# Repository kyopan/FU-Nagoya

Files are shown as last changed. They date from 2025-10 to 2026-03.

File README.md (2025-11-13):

**プロジェクトID**: FU

# Fragmentations of Unity (FU)

> 名古屋市芸術創造センター 群ロボットインスタレーション

---
project-type: customer
status: 🟢 稼働中
phase: Development
priority: Medium
start-date: 2025-10-13
updated: 2025-10-28
health: 🟢 正常
next-action: （要設定）
slack: ""
tags: []
---

## ステータス

- **フェーズ**: Development
- **開始日**: 2025-10-13
- **最終更新**: 2025-10-14
- **優先度**: High
- **外部共有リポジトリ**: [FU-Nagoya](https://github.com/kyopan/FU-Nagoya)

## 概要

**会場**: Common Nexus（ComoNe）

46個（または16個）の筒状ロボットが天井から吊り下げられ、ダクトレールシステムで制御されるインタラクティブ・インスタレーション。各ロボットは来場者を感知し、群としての振る舞いと個としての個性を表現します。言語を持たないロボットたちが、動きや光によって来場者とコミュニケーションを図ります。

米澤拓郎教授（名古屋大学）の「共有リアリティ」研究と連携し、異なる現実をつなぐインターリアリティを探求します。

## 目的

- 群行動の中に見える個性の表現
- 非言語コミュニケーションの探求
- インターリアリティ研究の実践
- 来場者とロボット群の相互作用の創出

## 主要機能

- Grid-EYE（8×8サーマルセンサー）による来場者検知
- マイクアレイによる空間トラッキング
- ダクトレール上の位置制御システム
- ポジティブ/ネガティブフィードバックループによる群行動
- 各ロボットの個性パラメータ設定

## 技術スタック

| カテゴリ | 技術 |
|---|---|
| マイコン | Arduino / ESP32-S3 |
| センサー | Grid-EYE（サーマルセンサー）、マイクアレイ |
| アクチュエーター | ダクトレール制御システム |
| 通信 | 無線通信（詳細未定） |

## ドキュメント

- [要件定義書](docs/requirements/INDEX.md)
- [仕様書](docs/specs/INDEX.md)
- [タスク管理](docs/tasks/INDEX.md)
- [ドキュメントインデックス](docs/INDEX.md)

## 購買管理

プロジェクトの購買・資材管理はGoogle Sheetsで一元管理しています。

**購買管理スプレッドシート**: [部品購入管理表](https://docs.google.com/spreadsheets/d/1netsUysI-VfH-YaXJFHr8gxybsaPnaWqvu3nM4HJtpM/edit?gid=0#gid=0)

管理項目:
- 購入品目・カテゴリ（電子部品/機械部品/材料/工具）
- 購入数・単価・送料（自動計算）
- 購入日・到着日・購入者
- 資金源（kyopalab/購入者立替/Crest）
- 購入リンク・コメント

## クイックスタート

```bash
# セットアップ手順
```

## チーム

- **米澤拓郎** - 名古屋大学（インターリアリティ研究）
- **菅野創** - 愛知県立芸術大学（ベルリン拠点、アーティスト）
- **興野悠太郎 (Kyopan)** - Kyopalab LLC（技術開発）

## 開発メモ

- 企画書: [米澤拓郎 + 菅野創+Kyopalab チーム 企画書.pdf](docs/米澤拓郎%20+%20菅野創+Kyopalab%20チーム%20企画書.pdf)
- 研究テーマ: 共有リアリティ（米澤教授）
- 展示会場: Common Nexus（ComoNe）

## 関連リンク

- [共通原則](../../shared/principles/README.md)
- [共通ユーティリティ](../../shared/utils/README.md)
- [グローバルルール](../../docs/rules/INDEX.md)

## ライセンス

(必要に応じて)

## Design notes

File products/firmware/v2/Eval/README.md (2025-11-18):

# FU v2 Eval Firmware

**作成日**: 2025-11-17
**ステータス**: Ready for testing
**目的**: v2基板完成までの評価テスト用にv1基板を流用

---

## 概要

v2ウインチ基板が正しく動作しない問題が発生したため、v1基板を流用して3台動作テストを実施するための評価ファームウェア。

**3つのファームウェア構成:**
1. `winch_esp32c6_eval` - ウインチ上部制御（ESP32-C6）
2. `winch_rp2040_eval` - ウインチ下部制御（Waveshare RP2040 Zero）
3. `tube_rp2040_eval` - 筒LED制御（Waveshare RP2040 Zero）

---

## ハードウェア構成

### 1. winch_esp32c6_eval
- **MCU**: ESP32-C6 DevKitM-1
- **役割**: Wi-Fi/MQTT通信、上下ユニット間通信制御
- **流用元**: v1 U1_mqtt

### 2. winch_rp2040_eval
- **MCU**: Waveshare RP2040-Zero
- **役割**: ステッパーモーター制御、ホーミング、2M上下動
- **流用元**: v1 FU_WINCH_RP2040_U2

### 3. tube_rp2040_eval
- **MCU**: Waveshare RP2040-Zero
- **役割**: NeoPixel LED制御（シリアル経由）
- **新規実装**: シリアルコマンドで色制御

---

## ビルド・書き込み手順

### 共通: PlatformIO CLI使用

```bash
# プロジェクトディレクトリに移動
cd products/firmware/v2/Eval

# ビルド
pio run -d [プロジェクト名]

# 書き込み
pio run -d [プロジェクト名] -t upload

# シリアルモニター起動
pio device monitor -d [プロジェクト名]
```

---

### 1. winch_esp32c6_eval

```bash
# ビルド
pio run -d winch_esp32c6_eval

# 書き込み
pio run -d winch_esp32c6_eval -t upload

# シリアルモニター（115200 baud）
pio device monitor -d winch_esp32c6_eval
```

**platformio.ini 設定:**
- Board: `esp32-c6-devkitm-1`
- Framework: Arduino
- Monitor speed: 115200

**主要機能:**
- Wi-Fi接続（SSID: FU）
- MQTT通信（Broker: 192.168.1.2）
- オンボードNeoPixel LED制御
- U2（RP2040）へのI2C通信

---

### 2. winch_rp2040_eval

```bash
# ビルド
pio run -d winch_rp2040_eval

# 書き込み
pio run -d winch_rp2040_eval -t upload

# シリアルモニター（115200 baud）
pio device monitor -d winch_rp2040_eval
```

**platformio.ini 設定:**
- Board: `waveshare_rp2040_zero`
- Framework: Arduino
- Monitor speed: 115200

**主要機能:**
- TMC2209ステッパー制御
- AccelStepperによる加減速制御
- ホーミングスイッチ検知
- 2M上下動（ランダムターン速度対応可能）
- ESP32C6からのI2C受信

**ピン配置:**
```cpp
PIN_TMC2209_EN    2
PIN_TMC2209_TX    0
PIN_TMC2209_RX    1
PIN_TMC2209_STEP  7
PIN_TMC2209_DIR   8
PIN_SENSOR        27  // ホーミングスイッチ
PIN_SOLENOID      26
PIN_U2_SDA        4
PIN_U2_SCL        5
```

---

### 3. tube_rp2040_eval

```bash
# ビルド
pio run -d tube_rp2040_eval

# 書き込み
pio run -d tube_rp2040_eval -t upload

# シリアルモニター（115200 baud）
pio device monitor -d tube_rp2040_eval
```

**platformio.ini 設定:**
- Board: `waveshare_rp2040_zero`
- Framework: Arduino
- Monitor speed: 115200

**ハードウェア設定（fu_v2_eval_board準拠）:**
- **NeoPixel LED**: GPIO 29
- **LED数**: 144個（72 LEDs × 2 strips）
  - 構成: 24×2 + 24×2 + 24×2 = 144 LEDs
- **Type**: NEO_GRB + NEO_KHZ800
- **Brightness**: 50/255 (デフォルト)

**主要機能:**
- NeoPixel LED制御（144個すべてに同一色設定）
- シリアルコマンドでRGB色制御

**シリアルコマンド:**
```
R<0-255>       - 赤色設定（例: R255）
G<0-255>       - 緑色設定（例: G128）
B<0-255>       - 青色設定（例: B0）
C<R>,<G>,<B>   - RGB一括設定（例: C255,100,0）
H              - ヘルプ表示
?              - 現在の色表示
```

**使用例:**
```
> R255
Red set to: 255
> G0
Green set to: 0
> B0
Blue set to: 0
Color set to RGB(255, 0, 0)  # 赤色

> C0,255,0
Color set to RGB(0, 255, 0)  # 緑色

> C100,150,200
Color set to RGB(100, 150, 200)  # 淡い青紫

> ?
Current color: RGB(100, 150, 200)
```

---

## 動作テスト手順

### Phase 1: 個別動作確認

#### ESP32-C6
```bash
1. winch_esp32c6_eval 書き込み
2. シリアルモニター起動
3. Wi-Fi接続確認（SSID: FU）
4. MQTT接続確認（Broker: 192.168.1.2）
5. オンボードLED点灯確認
```

#### RP2040 Winch
```bash
1. winch_rp2040_eval 書き込み
2. シリアルモニター起動
3. ホーミング動作確認（センサー検知）
4. 上昇動作確認（手動で距離測定）
5. 下降動作確認
6. ターン動作確認（速度変更）
```

#### RP2040 Tube
```bash
1. tube_rp2040_eval 書き込み
2. シリアルモニター起動
3. 初期化確認: "NeoPixel strip initialized on GPIO 29"
4. LED数確認: "LED count: 144"
5. コマンド "R255" → 全144個のLEDが赤色点灯確認
6. コマンド "G255" → 全144個のLEDが緑色点灯確認
7. コマンド "B255" → 全144個のLEDが青色点灯確認
8. コマンド "C255,100,50" → オレンジ色確認（全LED同一色）
9. グラデーションテスト（手動で複数色設定）
```

---

### Phase 2: 3台同時動作テスト

```bash
# 準備
1. 各ユニットを設置・配線
2. 電源投入順序: RP2040 Tube → RP2040 Winch → ESP32-C6
3. 各ユニットのシリアルモニター確認

# テスト実施
1. ホーミング動作（3台同時）
2. 2M上下動（ランダムターン速度）
3. LED発光パターン確認（tube_rp2040経由）
4. 風環境テスト（エアコン）
5. 30分連続動作テスト
```

**評価項目:**
- ベアリング+ケーブル耐環境性
- ホーミングスイッチ動作
- ウインチ静音性
- LED発光パターン
- 上下ユニット間通信

詳細: [v2-winch-eval-3units-test-spec.md](../../../docs/specs/v2-winch-eval-3units-test-spec.md)

---

## トラブルシューティング

### ビルドエラー

#### ESP32-C6: platform-espressif32エラー
```bash
# platform URLを最新に更新
[env:esp32-c6-devkitm-1]
platform = https://github.com/tasmota/platform-espressif32/releases/download/2024.09.10/platform-espressif32.zip
```

#### RP2040: platform-raspberrypiエラー
```bash
# platformを正しく指定
[env:waveshare_rp2040_zero]
platform = https://github.com/maxgerhardt/platform-raspberrypi.git
```

---

### 書き込みエラー

#### デバイスが認識されない
```bash
# macOS: デバイス確認
ls /dev/cu.*

# 権限確認
sudo chmod 666 /dev/cu.usbserial-*

# PlatformIO再起動
pio device list
```

#### RP2040: 書き込み方法

**通常の書き込み（BOOTSELボタン不要）:**
```bash
# PlatformIO picotoolが自動的にソフトリセットを実行
pio run -d winch_rp2040_eval_test -t upload
pio run -d tube_rp2040_eval_test -t upload
```

**BOOTSELモードが必要なケース（稀）:**
- 初回書き込み時
- USBデバイス認識失敗時
- ファームウェアクラッシュ時

```bash
1. BOOTSELボタンを押しながらUSB接続
2. RP2040がストレージデバイスとして認識
3. PlatformIOから書き込み実行
```

**理由:** `platformio.ini`の`upload_protocol = picotool`により、PlatformIOが自動的にRP2040へリセットコマンドを送信してブートローダーモードに入ります。

---

### 動作エラー

#### ESP32-C6: Wi-Fi接続失敗
```cpp
// SSID/パスワード確認
const char* ssid     = "FU";
const char* password = "spark!!!!!";
```

#### RP2040 Winch: ホーミング失敗
```cpp
// センサー閾値確認（globals変数）
int SENSOR_THRESHOLD = 250;

// ホーミング速度調整
long HOMING_SPEED = 500;
```

#### RP2040 Tube: LED点灯しない
```bash
# NeoPixel電源確認（RP2040 Zeroは自動）
# ピン番号確認
#define PIN_NEOPIXEL    16
```

---

## ファイル構造

```
Eval/
├── README.md                          # このファイル
├── winch_esp32c6_eval/
│   ├── platformio.ini
│   ├── src/
│   │   ├── main.cpp
│   │   ├── globals.h
│   │   ├── mqttClient.cpp
│   │   ├── mqttClient.h
│   │   ├── otaUpdater.cpp
│   │   └── otaUpdater.h
│   ├── include/
│   ├── lib/
│   └── test/
├── winch_rp2040_eval/
│   ├── platformio.ini
│   ├── src/
│   │   └── main.cpp                   # v1 FU_WINCH_RP2040_U2.ino移植
│   ├── include/
│   ├── lib/
│   └── test/
└── tube_rp2040_eval/
    ├── platformio.ini
    ├── src/
    │   └── main.cpp                   # シリアル色制御実装
    ├── include/
    ├── lib/
    └── test/
```

---

## 次のステップ

```markdown
[ ] 各ファームウェアのビルド確認
[ ] 各ユニットへの書き込み
[ ] 個別動作確認
[ ] 3台セットアップ
[ ] 動作テスト実施
[ ] 評価結果まとめ
[ ] v2基板改善へのフィードバック
```

---

## 参考資料

- [v2 動作テスト仕様書](../../../docs/specs/v2-winch-eval-3units-test-spec.md)
- [v1 Winch U1_mqtt](../../v1/Winch_v1/U1_mqtt/)
- [v1 Winch RP2040](../../v1/Winch_v1/FU_WINCH_RP2040_U2/)
- [PlatformIO Documentation](https://docs.platformio.org/)

---

## 変更履歴

| 日付 | 変更内容 | 担当 |
|---|---|---|
| 2025-11-17 | 初版作成（3つのEvalファームウェア） | CIC |

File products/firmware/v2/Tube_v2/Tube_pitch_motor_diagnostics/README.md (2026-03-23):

# Tube Pitch Motor Diagnostics 起動ガイド

## 目的
筒v2のUnit2のマイコンにUSB Cを接続し、水平キャリブレーションを行い、EEPROMに保存するプログラム。

本ツール（`pitch_diag.py`）を利用するための初期設定と起動方法について説明します。

## 1. パッケージの導入

本ツールはPythonを利用しています。以下のコマンドをターミナル（またはコマンドプロンプト）で実行し、必要なパッケージをインストールしてください。

```bash
pip install PyQt6 pyserial
```
※環境によっては `pip3 install PyQt6 pyserial` と入力してください。

## 2. 起動方法

ターミナルで `pitch_diag.py` があるディレクトリに移動し、以下のコマンドを実行します。

```bash
python pitch_diag.py
```
※環境によっては `python3 pitch_diag.py` と入力してください。

## 3. キャリブレーションの実行方法

GUI起動後、以下の手順でキャリブレーションを行います。

1. GUIを起動する
2. 筒v2のUnit2にUSB Cを挿して片方をPCに接続する（USB CケーブルがLEDリングや真鍮棒に引っかからないように工夫する）
3. 自動認識されるはずだが、されない場合は左上のメニューから`/cu/usbmodem.xxx`を選んでConnectボタンを押す
4. 筒を水平に保ち、青いボタン **Calibrate (Horizon)** を押す
5. キャリブレーション完了
6. 確認のためPitch Controlスライダー左右に動かすとPitchモーターが回転する

※Winchケーブルが繋がっていなくてもUSB電源のみで動作する

## 4. 導入・実行フロー図

```mermaid
graph TD
    A[Pythonのインストール確認] --> B[パッケージのインストール]
    B --> C[スクリプトの実行]
    C --> D[GUIの起動]
    D --> E[Unit2へUSB C接続]
    E --> F[ポート接続]
    F --> G[水平にしてCalibrate]
    G --> H[スライダーで動作確認]
```

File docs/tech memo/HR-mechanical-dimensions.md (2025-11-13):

# HR基板 機械寸法設計ワークシート

**作成日**: 2025-11-03
**担当**: kyopan
**目的**: HR（Horizontal Ring）基板の機械寸法を確定し、PR基板設計の基準を提供

---

## 📐 寸法設定の前提条件

### V1仕様（参考値）
- **筒直径**: 76mm
- **筒長さ**: 300mm

### 制約条件
1. **筒直径**: 76mm内に収める必要がある
2. **中心部**: Pitch軸機構 + YAW BLDC配置
3. **外周部**: PRリング取り付けスペース
4. **スリップリング**: 上部中心配置
5. **配線**: ウィンチケーブル、モーター配線等

---

## 🎯 HR基板の役割（再確認）

### 構造的役割
- **水平固定基板**: 常に水平、回転しない
- **ウィンチ接続**: スリップリング経由で電源・通信
- **モーター取り付け**: YAW BLDC（真下）、Pitch BLDC
- **PR支持**: PRリングをPitch軸で±60°回転可能に支持

### 電気的役割
- **電源供給**: 24V入力 → 5V変換 → 全基板へ供給
- **マイコン搭載**: ESP32-S3 #1, #2
- **モーター制御**: Pitch/YAW BLDC制御回路
- **エンコーダー接続**: Pitch/YAW/DIRエンコーダー

---

## 📏 寸法検討

### 1. HR基板外径

**制約:**
- 筒直径76mm内に収める
- PCB厚さ1.6mm
- 筒内壁とのクリアランス必要（振動・組立誤差考慮）

**検討:**
```
筒内径: 76mm
クリアランス: 2mm（片側1mm × 2）
HR基板最大外径: 74mm
→ 提案: 70mm（余裕を持たせる）
```

**質問:**
- YAW BLDCの直径は？
- Pitch軸機構の外径は？
- これらを考慮して、HR外径は何mmが適切？

### 2. HR基板内径（中心穴）

**配置するもの（中心部）:**
- スリップリング（直径: TBD mm）
- Pitch軸機構
- 配線通路

**検討:**
```
スリップリング直径: TBD mm
Pitch軸ベアリング直径: TBD mm
配線クリアランス: 5mm
HR基板内径: TBD mm
```

**質問:**
- スリップリングの直径は？
- Pitch軸機構の必要径は？

### 3. PRリング取り付け領域

**HR外周部の構造:**
```
[HR基板]
  外径: 70mm（仮）
  PRリング取り付け位置: 外周

[PRリング]
  内径: HR外径 + クリアランス
  外径: 筒内径 - クリアランス
```

**検討:**
```
HR外径: 70mm（仮）
PRリング内径: 72mm（2mmクリアランス）
PRリング外径: 74mm（筒内壁から2mm）
PRリング幅: 1mm（狭い！）
→ 再検討必要
```

**質問:**
- PRリングは何mm幅必要？
  - 真鍮線接続点×12を配置
  - 配線経路確保
  - 構造強度
- HR外径とPRリング内径の関係は？

### 4. Pitch軸回転機構

**機構:**
```
HR基板（固定）
  ↓ Pitch軸（±60°回転）
PRリング（回転）
```

**検討事項:**
- Pitch軸はHR中心に配置？
- Pitch BLDCはHR上に固定？
- PRリングとの接続は？（ベアリング？軸受け？）
- 可変抵抗の取り付け位置は？

### 5. 部品配置計画

#### HR基板上に配置する部品
- [ ] スリップリング（中心）
- [ ] ESP32-S3 #1（どこ？）
- [ ] ESP32-S3 #2（どこ？）
- [ ] 24V→5V DCDC（何mm × 何mm？）
- [ ] Pitch BLDC接続コネクタ
- [ ] YAW BLDC接続配線（真下に通す）
- [ ] Pitch/YAW/DIRエンコーダー接続
- [ ] PR接続コネクタ（外周）

**配置エリア計算:**
```
HR基板面積: π × (外径/2)² - π × (内径/2)²
例: 外径70mm、内径30mmの場合
  = π × 35² - π × 15²
  = 3848 - 707
  = 3141 mm²
```

**質問:**
- ESP32-S3モジュールのサイズは？（何mm × 何mm？）
- DCDCモジュールのサイズは？
- 全部品が収まる？

---

## 🔧 取り付け穴・ネジ配置

### HRの取り付け方法
- ウィンチケーブルから懸架？
- 何点支持？
- ネジ径・位置は？

### PR取り付け穴
- Pitch軸中心に何点？
- ネジ径・位置は？

---

## 📊 寸法サマリー（仮）

| 項目 | 寸法（仮） | 確定状況 | 備考 |
|---|---|---|---|
| HR外径 | 70mm | 要確認 | 筒内径76mmの制約 |
| HR内径 | 30mm | 要確認 | スリップリング+Pitch軸 |
| HR厚さ | 1.6mm | 確定 | 標準FR-4 |
| PRリング内径 | 72mm | 要確認 | HR外径+2mm |
| PRリング外径 | 74mm | 要確認 | 筒内径-2mm |
| PRリング幅 | 1mm | 要検討 | 狭すぎる可能性 |
| 筒直径 | 76mm | V1仕様 | 変更無し？ |

---

## 🤔 設計判断が必要な項目

### 優先度: 高
1. **HR外径**: 何mm？（部品配置可能性の確認）
2. **PRリング幅**: 何mm必要？（真鍮線×12配置可能性）
3. **スリップリング直径**: 何mm？（HR内径に影響）
4. **Pitch軸機構**: どういう構造？（機械図面必要）

### 優先度: 中
5. ESP32-S3モジュールサイズ
6. DCDCモジュールサイズ
7. 各種コネクタ配置
8. 配線経路

---

## 📐 寸法確定の手順

### ステップ1: 中心部の決定
1. スリップリング直径確認
2. Pitch軸機構の必要径確認
3. HR内径決定

### ステップ2: 外周部の決定
1. 部品配置エリア計算
2. ESP32-S3、DCDC等のサイズ確認
3. 配置可能性確認
4. HR外径決定

### ステップ3: PRリング寸法の決定
1. HR外径確定後、PRリング内径決定
2. 真鍮線×12配置の必要幅確認
3. PRリング幅決定
4. PRリング外径決定（筒内径との整合性確認）

### ステップ4: 取り付け穴の決定
1. Pitch軸取り付け位置
2. ウィンチ懸架用取り付け穴
3. その他必要な取り付け穴

---

## 🛠️ 次のアクション

### 即座に必要な情報
1. **スリップリング仕様**
   - 直径
   - 高さ
   - 取り付け方法

2. **モーター仕様**
   - YAW BLDC直径・高さ
   - Pitch BLDC直径・高さ
   - 取り付け方法

3. **Pitch軸機構**
   - 機械設計図面
   - 必要なクリアランス
   - ベアリング・軸受けの仕様

4. **ESP32-S3モジュール**
   - 使用するモジュール型番
   - サイズ（mm × mm）

5. **DCDCモジュール**
   - 使用する型番
   - サイズ（mm × mm）

### CAD作業
- [ ] 機械寸法確定後、2D CAD図面作成
- [ ] 3Dモデル作成（FreeCAD/Fusion360等）
- [ ] 干渉チェック

---

## 📝 メモ・気づき

- PRリング幅1mmは狭すぎる可能性
  - 真鍮線×12の配置が困難
  - 構造強度不足の可能性
  - HR外径を小さくしてPRリング幅を確保する方が良い？

- 筒直径76mmは変更不可？
  - V1と同じ径を維持する理由は？
  - 変更可能なら、余裕を持たせられる

- Pitch軸機構の詳細が不明
  - 機械設計の進捗確認必要
  - 鈴木さんとの連携

---

**作成者**: CIC
**ステータス**: 寸法確定作業中
**次回更新**: 機械設計完了後

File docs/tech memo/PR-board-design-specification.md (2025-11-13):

# PR基板（Pitch Ring）設計仕様書 V2

**作成日**: 2025-11-03
**プロジェクト**: Fragmentations of Unity (FU@ComoNe)
**展示日**: 2025-12-20
**担当**: kyopan

---

## 📋 文書情報

| 項目 | 内容 |
|---|---|
| **基板名** | PR (Pitch Ring) - 本番用V2 |
| **形状** | リング状（円環）基板 |
| **役割** | Pitch軸回転ベース、GR/CR支持構造、配線中継 |
| **ステータス** | 設計開始前 |

---

## 🎯 PR基板の役割

### 1. 構造的役割
- **Pitch軸回転機構**: HRの外周にリング状に取り付け、±60°傾斜可能
- **GR/CR支持**: 真鍮線を介してGridEye Ring（GR）とCompass Ring（CR）を接続
- **筒構造維持**: 筒全体の機械的強度を保つ骨格

### 2. 電気的役割
- **配線中継**: HR（FR）からGR/CRへの電源・信号中継
- **真鍮線接続点**: 12点の真鍮線接続（前面6点、背面6点）
- **Pitchモーター接続**: Pitch BLDCとの電気的接続

---

## 🏗️ 全体構造の理解

### 基板構成（修正版）

```
┌─────────────────────────────┐
│ HR (Horizontal Ring)         │ ← 水平固定、常に水平
│ = FR (Flat Ring)と同義       │
│ - ウィンチケーブル接続        │
│ - スリップリング              │
│ - ESP32-S3 #1, #2            │
│ - 24V→5V DCDC                │
│ - YAW BLDC（真下配置）        │
│ - Pitch BLDC                 │
└─────────────────────────────┘
         ↓ ±60°傾斜可能
┌─────────────────────────────┐
│ PR (Pitch Ring) ← 本設計対象  │ ← リング状、HRの外周
│ - 真鍮線接続点 12箇所         │
│ - GR/CR支持構造               │
│ - 配線中継                    │
└─────────────────────────────┘
         ↓ 真鍮線接続
┌─────────────────────────────┐
│ GR (GridEye Ring)            │ ← 評価ボード流用
│ - Grid-EYE ×2                │
│ - NeoPixel前面               │
│ - 5V→3.3V DCDC               │
└─────────────────────────────┘
         ↓ 真鍮線接続
┌─────────────────────────────┐
│ CR (Compass Ring)            │ ← 評価ボード流用
│ - AS5600（DIR）              │
│ - GY-85 IMU                  │
│ - NeoPixel背面               │
│ - 5V→3.3V DCDC               │
└─────────────────────────────┘
```

### 用語統一
- **HR (Horizontal Ring)** = **FR (Flat Ring)**: 同一基板を指す
  - 以後、HRで統一
  - 水平円形基板、常に水平、ウィンチケーブル接続点

---

## 🔌 真鍮線配線仕様（配線図より）

### 前面側（GR Front → PR Front → GR Back）

| 線番号 | 信号名 | 用途 | 経路 |
|---|---|---|---|
| W2_3 | NeoPixel Data (Front) | GRF NeoPixel制御 | GRF Ns3 → PRF Ns1 → GRB CB |
| W4_5 | NeoPixel Data (Back) | GRB NeoPixel制御 | GRF Ns4 → PRF Ns2 → GRB CB |
| SDA0 | I2C Data (Front Grid-EYE) | Grid-EYE #1 | GRF GridEye3 → PRF GR.PCB → GRB GR.PCB |
| SCL0 | I2C Clock (Front Grid-EYE) | Grid-EYE #1 | GRF GridEye3 → PRF GR.PCB → GRB GR.PCB |
| 5V | 電源 | 全基板共通 | 全基板接続 |
| GND | グランド | 全基板共通 | 全基板接続 |

### 背面側（CR Front → PR Back → CR Back）

| 線番号 | 信号名 | 用途 | 経路 |
|---|---|---|---|
| W6 | NeoPixel Data (Back) | CRF/CRB NeoPixel制御 | W6 → PRB → CRB |
| SDA1 | I2C Data (AS5600 + GY-85) | DIR Encoder + IMU | CRF → PRB → CRB |
| SCL1 | I2C Clock (AS5600 + GY-85) | DIR Encoder + IMU | CRF → PRB → CRB |
| W4_5 | NeoPixel Data | GR側から延長 | PRF → PRB → CRB |
| 5V | 電源 | 全基板共通 | 全基板接続 |
| GND | グランド | 全基板共通 | 全基板接続 |

### PR基板上の真鍮線接続点

**PRF (PR Front) - 6点:**
1. W2_3 入力 (GRF Ns3)
2. W4_5 入力 (GRF Ns4)
3. SDA0 (Grid-EYE #1)
4. SCL0 (Grid-EYE #1)
5. 5V
6. GND

**PRB (PR Back) - 6点:**
1. W6 入力
2. SDA1 (AS5600 + GY-85)
3. SCL1 (AS5600 + GY-85)
4. W4_5 中継
5. 5V
6. GND

**合計: 12接続点**

---

## ⚙️ モーター・エンコーダー配置

### Pitch BLDC + エンコーダー
- **配置**: HR上に取り付け
- **役割**: PR（リング）を±60°傾斜させる
- **エンコーダー**: AS5600（PB基板上、HRに垂直取り付け）
- **制御**: ESP32-S3 #2 Core 1

### YAW BLDC + エンコーダー
- **配置**: HRの真下
- **役割**: リアクションホイール、ケーブルねじれ補正
- **エンコーダー**: AS5600（CR基板上、DIRエンコーダーとは別）
- **制御**: ESP32-S3 #2 Core 2

### DIR（方向）エンコーダー
- **配置**: ミニプラグメス（スリップリング部）に取り付け
- **役割**: コンパス代替、筒全体の回転方向検出
- **エンコーダー**: AS5600
- **制御**: ESP32-S3 #2 Core 2

---

## 🔧 ESP32-S3 配置・役割（確定版）

### ESP32-S3 #1（HR基板上）
| コア | 役割 | 通信先 |
|---|---|---|
| Core 1 | ウィンチ基板との通信<br/>ESP32-S3 #2との通信 | UART（ウィンチ）<br/>UART/SPI（S3 #2） |
| Core 2 | LED制御（NeoPixel全体）<br/>GridEye制御（Grid-EYE ×2）<br/>GY85制御（使わない可能性） | I2C（Grid-EYE via 真鍮線）<br/>I2C（GY-85 via 真鍮線） |

### ESP32-S3 #2（HR基板上）
| コア | 役割 | 制御対象 |
|---|---|---|
| Core 1 | Pitchモーター制御<br/>Pitchエンコーダー制御 | Pitch BLDC<br/>AS5600（PB基板） |
| Core 2 | YAWモーター制御<br/>YAWエンコーダー制御<br/>DIRエンコーダー制御 | YAW BLDC<br/>AS5600（CR基板）<br/>AS5600（スリップリング部） |

---

## 📐 PR基板設計要件

### 1. 機械的要件

#### 形状
- **基本形状**: リング状（円環）
- **外径**: TBD mm（HRの外周に収まるサイズ）
- **内径**: TBD mm（Pitch軸機構を通すクリアランス）
- **厚さ**: 1.6mm（標準FR-4基板）

#### 取り付け
- **HR接続**: Pitch軸を中心に±60°回転可能
- **GR接続**: 真鍮線×6本（前面）
- **CR接続**: 真鍮線×6本（背面）

#### 構造強度
- 筒全体の構造を支える強度が必要
- GR（約XXg）+ CR（約XXg）の重量を支持

### 2. 電気的要件

#### 電源
- **入力**: 5V（HRから供給）
- **出力**: 5V（GR/CRへ供給）
- **電流容量**: TBD A（GR/CR消費電流 + 余裕）

#### 信号線
- **I2C×2系統**: SDA0/SCL0（Grid-EYE）、SDA1/SCL1（AS5600+GY-85）
- **NeoPixel×3系統**: W2_3、W4_5、W6
- **GND**: 共通グランド

#### ノイズ対策
- 真鍮線による信号伝送のため、ノイズ対策必須
- I2C信号のプルアップ抵抗（HR側に実装済み？確認要）
- GNDプレーン確保

### 3. 接続要件

#### HR側接続
- **コネクタ方式**: TBD（フレキシブルケーブル？ピンヘッダ？）
- **信号数**: 5V、GND、I2C×2系統、NeoPixel×3系統 = 最低9ピン

#### GR側接続（前面6点）
- 真鍮線用ランド
- 半田付けまたは圧着端子

#### CR側接続（背面6点）
- 真鍮線用ランド
- 半田付けまたは圧着端子

---

## 📊 評価PR vs 本番PRの差分

| 項目 | 評価PR | 本番PR |
|---|---|---|
| **形状** | 円形板 | リング状 |
| **HR連携** | 無し | 有り（±60°回転） |
| **真鍮線接続** | 有り（テスト用） | 有り（本番配置） |
| **モーター接続** | 無し | Pitch BLDC接続考慮 |
| **マイコン配置** | 考慮なし | HR上のS3配置に最適化 |
| **用途** | 通信・LED・耐久性テスト | 本番展示 |

---

## 🛠️ 設計スコープ

### 本タスクで設計するもの
1. **PR基板回路図**
   - 真鍮線接続点×12の配置
   - 電源・信号経路設計
   - コネクタ選定

2. **PR基板PCBレイアウト**
   - リング状基板設計
   - ランド配置（真鍮線接続用）
   - GNDプレーン設計
   - 機械的取り付け穴

3. **BOM（部品表）**
   - コネクタ
   - 真鍮線用ランド
   - その他部品

### 本タスクで設計しないもの
- HR基板設計（別途設計が必要）
- PB基板設計（Pitchエンコーダー専用、必要性確認要）
- GR基板（評価ボード流用、完成品）
- CR基板（評価ボード流用、完成品）
- ファームウェア設計

---

## 📅 開発スケジュール（暫定）

### Phase 1: 要件定義・詳細仕様（11/3-11/5）
- [x] 配線図確認
- [ ] HR基板との接続方式確定
- [ ] 機械寸法確定（外径、内径、取り付け穴）
- [ ] コネクタ選定

### Phase 2: 回路設計（11/6-11/10）
- [ ] 回路図作成（EasyEDA等）
- [ ] 信号経路設計
- [ ] ノイズ対策設計

### Phase 3: PCB設計（11/11-11/20）
- [ ] PCBレイアウト設計
- [ ] リング形状最適化
- [ ] DRC（Design Rule Check）
- [ ] レビュー（鈴木さん、菅野さん）

### Phase 4: 発注・製造（11/21-11/30）
- [ ] PCB発注（JLCPCB等）
- [ ] 部品発注
- [ ] 納品待ち

### Phase 5: 組み立て・検証（12/1-12/10）
- [ ] PCB組み立て
- [ ] 真鍮線半田付け
- [ ] 単体動作テスト
- [ ] GR/CR接続テスト

### Phase 6: 統合テスト（12/11-12/15）
- [ ] HR-PR-GR-CR統合テスト
- [ ] Pitch回転テスト
- [ ] 通信・LED動作確認

### Phase 7: 量産準備（12/16-12/19）
- [ ] 46台製作
- [ ] 品質検査
- [ ] 現地搬入

---

## 🧪 テスト項目

### 1. 電気的テスト
- [ ] 5V電源供給確認（HR → PR → GR/CR）
- [ ] GND導通確認
- [ ] I2C信号品質確認（オシロスコープ）
- [ ] NeoPixel信号品質確認

### 2. 機械的テスト
- [ ] Pitch回転±60°動作確認
- [ ] 真鍮線接続強度テスト
- [ ] 振動耐久テスト

### 3. 統合テスト
- [ ] HR-PR間回転時の信号断線チェック
- [ ] LED全点灯テスト
- [ ] Grid-EYE動作確認
- [ ] AS5600（DIR）動作確認

---

## 📝 確定事項

### 設計担当・ツール
- ✅ **HR基板設計**: kyopan担当
- ✅ **設計ツール**: EasyEDA
- ✅ **PCB厚さ**: 1.6mm（PR/CR共通）

### 電気仕様
- ✅ **I2Cプルアップ抵抗**: ESP32-S3内部プルアップ使用

### 製造・組立
- ✅ **真鍮線接続**: 治具を作成して半田付け
- ✅ **評価PR到着**: 3日後（11/6予定）

### 評価PR検証項目
- ✅ 筒を被せてLEDの光り方確認
- ✅ ウィンチモジュールの耐久性確認
- ✅ 通信チェック

## 📝 未確認事項・TODO

### 機械設計（作成中）
- [ ] PR基板の外径・内径寸法
- [ ] リング幅
- [ ] Pitch軸機構の詳細（機械設計図面）
- [ ] 取り付け穴位置・径

### 部品選定
- [ ] PR-HR間接続方式（コネクタ型番）
- [ ] 真鍮線の線径・材質
- [ ] 半田付け治具の設計

---

## 🔗 関連ドキュメント

- [tube-body-v2-implementation-plan.md](tube-body-v2-implementation-plan.md) - 全体実装計画
- [tube-body-v2-structure-understanding.md](tube-body-v2-structure-understanding.md) - 構造理解
- [PR-board-WBS.md](PR-board-WBS.md) - PR基板設計WBS
- [HR-mechanical-dimensions.md](HR-mechanical-dimensions.md) - HR基板機械寸法ワークシート
- [evaluation-PR-verification-plan.md](evaluation-PR-verification-plan.md) - 評価PR検証計画
- [../../notes/actuar-wiring-2025-10-23.png](../../notes/actuar-wiring-2025-10-23.png) - 配線図
- [../specs/winch-circuit-design-v2.md](../specs/winch-circuit-design-v2.md) - ウィンチ基板仕様

---

## ✅ レビュー承認

| 役割 | 氏名 | 日付 | 署名 |
|---|---|---|---|
| 設計 | kyopan | | |
| レビュー（電気） | 鈴木さん | | |
| レビュー（アート） | 菅野さん | | |
| 承認 | | | |

---

**作成者**: CIC
**ステータス**: 設計仕様確定待ち

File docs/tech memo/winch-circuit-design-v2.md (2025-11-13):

# Winch回路設計仕様書

## 📋 文書情報

| 項目 | 内容 |
|---|---|
| **バージョン** | V2.0（Draft） |
| **作成日** | 2025-10-16 |
| **作成者** | kyopan |
| **最終更新** | 2025-10-16 |
| **ステータス** | Draft |

## 🎯 目的

FU@ComoNeプロジェクトにおける筒ロボット制御用ウィンチシステムの回路設計仕様を定義する。

## 📊 プロジェクト概要

| 項目 | 内容 |
|---|---|
| **台数** | 60台（本番46台 + 予備14台） |
| **設置場所** | Common Nexus（ComoNe）天井 |
| **制御対象** | 筒ロボット（垂直昇降） |
| **通信** | 筒基板との双方向通信（24V電源 + データ） |

## 🔧 ハードウェア要件

### 1. 電源仕様

| 項目 | 仕様 | 備考 |
|---|---|---|
| **入力電源** | AC100V または DC24V | 環境に応じて選択 |
| **出力電源** | DC24V | 筒基板への供給 |
| **最大電流** | TBD A | 負荷計算後に決定 |
| **電源保護** | 過電流保護、逆接続保護 | 必須 |

### 2. モーター仕様

| 項目 | 仕様 | 備考 |
|---|---|---|
| **モータータイプ** | ステッピングモーター or DCモーター | TBD |
| **トルク** | TBD Nm | 筒重量 × 1.2倍 |
| **速度** | TBD rpm | 昇降速度から算出 |
| **エンコーダー** | あり/なし | 位置フィードバック用 |

### 3. モータードライバ

| 項目 | 仕様 | 備考 |
|---|---|---|
| **型番** | TBD | ステッピング/DC対応 |
| **制御方式** | PWM / Step/Dir | モーター種別に応じて |
| **電流制限** | TBD A | モーター定格に合わせる |
| **過熱保護** | あり | 安全機能 |

### 4. マイコン

| 項目 | 仕様 | 備考 |
|---|---|---|
| **型番** | ESP32-S3 or Arduino | TBD |
| **GPIO数** | 最低10ピン | モーター制御、通信、センサー用 |
| **通信** | UART（筒基板との通信） | TX/RX |
| **電源電圧** | 3.3V / 5V | ロジックレベル |

### 5. 通信インターフェース

#### 筒基板との通信

| 項目 | 仕様 | 備考 |
|---|---|---|
| **物理層** | ステレオ4極ジャック | ケーブル経由 |
| **信号** | 24V電源 + UART（TX/RX） | 4線（GND, 24V, TX, RX） |
| **ボーレート** | TBD bps | 9600 or 115200 |
| **プロトコル** | カスタム | 双方向通信 |

#### 親機との通信（オプション）

| 項目 | 仕様 | 備考 |
|---|---|---|
| **通信方式** | Wi-Fi / 有線LAN / RS485 | TBD |
| **用途** | 制御指令、ステータス監視 | 集中管理 |

### 6. センサー

| 項目 | 仕様 | 備考 |
|---|---|---|
| **上限リミットスイッチ** | あり | 安全停止 |
| **下限リミットスイッチ** | あり | 安全停止 |
| **エンコーダー** | オプション | 位置フィードバック |
| **電流センサー** | オプション | 過負荷検知 |

### 7. 安全機構

| 項目 | 仕様 | 備考 |
|---|---|---|
| **緊急停止ボタン** | あり | 物理ボタン |
| **ソフトウェアリミット** | あり | ファームウェアで制御 |
| **過電流保護** | あり | ヒューズ or 電子保護 |
| **ウォッチドッグタイマー** | あり | マイコンリセット機能 |

## 📐 回路構成

### ブロック図

```
[AC100V/DC24V] → [電源回路] → [24V出力]
                      ↓
              [マイコン(ESP32/Arduino)]
                      ↓
          ┌───────────┼───────────┐
          ↓           ↓           ↓
    [モータードライバ] [通信回路] [センサー入力]
          ↓           ↓
      [モーター]   [筒基板]
                  (ステレオ4極)
```

### 主要回路

#### 1. 電源回路
- AC100V → DC24V 変換（AC-DCコンバータ）
- または DC24V入力（外部電源）
- 24V → 5V/3.3V 降圧（マイコン用）
- 逆接続保護ダイオード
- 過電流保護ヒューズ

#### 2. マイコン回路
- ESP32-S3 or Arduino
- クリスタル発振子
- リセット回路
- デバッグ用UART
- GPIO保護回路

#### 3. モーター制御回路
- モータードライバIC
- PWM入力
- 電流センシング（オプション）
- 逆起電力保護

#### 4. 通信回路
- UART → ステレオ4極ジャック
- ESD保護回路（TX/RX）
- プルアップ/プルダウン抵抗
- 24V電源供給ライン

#### 5. センサー入力回路
- リミットスイッチ × 2（上限/下限）
- プルアップ抵抗
- ノイズフィルタ

## 🔌 コネクタ仕様

### 1. 筒基板接続（ステレオ4極ジャック）

| ピン | 信号 | 備考 |
|---|---|---|
| Tip | TX | ウィンチ → 筒 |
| Ring1 | RX | 筒 → ウィンチ |
| Ring2 | 24V | 電源供給 |
| Sleeve | GND | 共通グランド |

### 2. 電源入力

| ピン | 信号 | 備考 |
|---|---|---|
| 1 | AC100V/DC24V+ | 電源入力 |
| 2 | GND | グランド |

### 3. モーター接続

| ピン | 信号 | 備考 |
|---|---|---|
| TBD | モーター信号 | モーター種別に応じて |

## 📏 物理仕様

| 項目 | 仕様 | 備考 |
|---|---|---|
| **基板サイズ** | TBD mm × TBD mm | 設置スペースに応じて |
| **取付方法** | ネジ止め or DINレール | 天井設置を考慮 |
| **防水性** | IP20以上 | 屋内使用 |
| **動作温度** | 0℃〜40℃ | 会場環境 |

## 🧪 テスト項目

### 1. 電源テスト
- [ ] 入力電圧範囲テスト
- [ ] 出力電圧安定性テスト
- [ ] 過電流保護動作確認
- [ ] 逆接続保護動作確認

### 2. モーター制御テスト
- [ ] モーター駆動確認
- [ ] 速度制御精度テスト
- [ ] トルク測定
- [ ] 連続運転テスト（1時間）

### 3. 通信テスト
- [ ] 筒基板との通信確認
- [ ] データ送受信エラーレート測定
- [ ] ケーブル断線検知テスト
- [ ] ノイズ耐性テスト

### 4. センサーテスト
- [ ] リミットスイッチ動作確認
- [ ] エンコーダー精度テスト（オプション）
- [ ] 電流センサー精度テスト（オプション）

### 5. 安全機能テスト
- [ ] 緊急停止ボタン動作確認
- [ ] ソフトウェアリミット動作確認
- [ ] ウォッチドッグタイマー動作確認

### 6. 耐久テスト
- [ ] 連続昇降テスト（24時間）
- [ ] 温度上昇測定
- [ ] 長期動作安定性テスト（1週間）

## 📝 設計メモ

### V1からの改良点
- [ ] 電源効率の向上
- [ ] ノイズ対策の強化
- [ ] コネクタの脱落防止対策
- [ ] 基板サイズの最適化
- [ ] コスト削減

### 検討事項
- [ ] モーター種別の決定（ステッピング vs DC）
- [ ] エンコーダーの必要性
- [ ] 親機通信方式の決定
- [ ] 筒重量の最終確定
- [ ] ケーブル長の最大値

### リスク
- [ ] ケーブル断線リスク → 耐久テストで評価
- [ ] 電源ノイズによる通信エラー → ESD保護・ノイズフィルタ
- [ ] モーター過熱 → 温度センサー追加検討
- [ ] 設置環境の制約 → 現地調査必要

## 🔗 関連ドキュメント

- [evaluation-board-design.md](../tasks/evaluation-board-design.md) - 筒評価ボード仕様
- [arduino-pullup-resistor-lecture.md](../../notes/arduino-pullup-resistor-lecture.md) - プルアップ抵抗の説明
- V1 EasyEDAファイル: [リンク](https://pro.easyeda.com/editor#id=91112fbff8f44189b064c06750374ec7)

## 📅 更新履歴

| 日付 | バージョン | 変更内容 | 担当 |
| --- | --- | ---- | --- |
| 2025-10-16 | V2.0 Draft | 初版作成 | kyopan |

---

## ✅ レビュー承認

| 役割 | 氏名 | 日付 | 署名 |
|---|---|---|---|
| 設計 | kyopan | | |
| レビュー | Hirano | | |
| 承認 | | | |

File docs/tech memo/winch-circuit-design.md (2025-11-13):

# Winch回路設計仕様書

## 📋 文書情報

| 項目 | 内容 |
|---|---|
| **バージョン** | V2.0（Draft） |
| **作成日** | 2025-10-16 |
| **作成者** | kyopan |
| **最終更新** | 2025-10-16 |
| **ステータス** | Draft |

## 🎯 目的

FU@ComoNeプロジェクトにおける筒ロボット制御用ウィンチシステムV2の回路設計仕様を定義する。

**V2の設計方針**: V1で実証した機能を維持しつつ、基板統合・構造シンプル化・コスト削減・メンテナンス性向上を実現

## 📊 プロジェクト概要

| 項目 | 内容 |
|---|---|
| **台数** | 60台（本番46台 + 予備14台） |
| **設置場所** | Common Nexus（ComoNe）天井・照明用ダクトレール固定 |
| **制御対象** | 筒ロボット（垂直昇降、最大3メートル） |
| **通信** | 筒基板との双方向通信（24V電源 + UART） |
| **V1実績** | 動作実証完了、7枚基板構成の簡素化が必要 |
| **制御可能台数** | 最大128台（Wi-Fi経由） |

## 🔧 ハードウェア要件

### 1. 電源仕様

| 項目 | V1実績 | V2目標 | 備考 |
|---|---|---|---|
| **入力電源** | AC100V（ダクトレール） | AC100V or DC24V | V2: 外部DC24V入力も検討 |
| **出力電源** | DC 24V / 5V | DC 24V / 5V | 筒基板24V、制御回路5V |
| **最大電流** | TBD A | TBD A | 負荷計算後に決定 |
| **電源変換** | AC→DC変換内蔵 | **V2: 簡素化検討** | DC入力のみで統一可能性 |
| **電源保護** | 過電流保護 | 過電流保護、逆接続保護 | 必須 |

### 2. モーター仕様（昇降用）

| 項目 | V1実績 | V2目標 | 備考 |
|---|---|---|---|
| **モータータイプ** | **低騒音ステッピングモーター** | ステッピングモーター | V1実績を継承 |
| **トルク** | TBD Nm | TBD Nm | 筒重量 × 1.2倍 |
| **速度** | TBD rpm | TBD rpm | 昇降速度から算出 |
| **エンコーダー** | なし | オプション検討 | 位置フィードバック精度向上 |
| **非常ブレーキ** | **ソレノイド式** | **V2: 代替方式検討** | 電源断時の筒落下防止 |

### 3. モータードライバ

| 項目 | 仕様 | 備考 |
|---|---|---|
| **型番** | TBD | ステッピング/DC対応 |
| **制御方式** | PWM / Step/Dir | モーター種別に応じて |
| **電流制限** | TBD A | モーター定格に合わせる |
| **過熱保護** | あり | 安全機能 |

### 4. マイコン

| 項目 | V1実績 | V2目標 | 備考 |
|---|---|---|---|
| **型番** | TBD | ESP32-S3 推奨 | Wi-Fi内蔵、GPIO豊富 |
| **GPIO数** | 最低10ピン | 最低15ピン | モーター、通信、センサー、LED |
| **Wi-Fi** | **搭載** | **搭載（必須）** | 最大128台制御 |
| **通信（筒）** | UART（TX/RX） | UART（TX/RX） | 双方向通信 |
| **電源電圧** | 3.3V / 5V | 3.3V / 5V | ロジックレベル |

### 5. 通信インターフェース

#### 筒基板との通信

| 項目 | V1実績 | V2目標 | 備考 |
|---|---|---|---|
| **物理層** | RS485 | **UART（簡素化）** | ステレオ4極ジャック |
| **信号** | RS485 + 24V電源 | **24V + UART（TX/RX）** | 4線（GND, 24V, TX, RX） |
| **ボーレート** | TBD bps | 115200 bps推奨 | 高速通信 |
| **プロトコル** | カスタム | カスタム | 双方向通信 |
| **ケーブル長** | **最大3メートル** | 最大3メートル | スリップリング経由 |
| **ESD保護** | 必要 | **必須** | TX/RXにESD保護回路 |

#### 親機との通信

| 項目 | V1実績 | V2目標 | 備考 |
|---|---|---|---|
| **通信方式** | **Wi-Fi** | **Wi-Fi** | 最大128台制御可能 |
| **用途** | 制御指令、ステータス監視 | 制御指令、ステータス監視 | 集中管理 |
| **通信品質** | 実証済み | 継承 | ノイズ耐性確認済み |

### 6. センサー

| 項目 | V1実績 | V2目標 | 備考 |
|---|---|---|---|
| **筒位置検知** | **赤外線式** | 赤外線式継承 | 筒の位置検知・原点合わせ |
| **上限リミットスイッチ** | TBD | 検討 | 安全停止 |
| **下限リミットスイッチ** | TBD | 検討 | 安全停止 |
| **エンコーダー** | なし | オプション | 位置フィードバック精度向上 |
| **電流センサー** | なし | オプション | 過負荷検知・予防保全 |

### 7. 安全機構

| 項目 | V1実績 | V2目標 | 備考 |
|---|---|---|---|
| **非常ブレーキ** | **ソレノイド式** | **代替方式検討** | 電源断時の筒落下防止（必須） |
| **緊急停止** | あり | あり | 物理ボタン or ソフトウェア |
| **ソフトウェアリミット** | あり | あり | ファームウェアで制御 |
| **過電流保護** | あり | あり | ヒューズ or 電子保護 |
| **ウォッチドッグタイマー** | あり | あり | マイコンリセット機能 |

### 8. 照明機能

| 項目 | V1実績 | V2目標 | 備考 |
|---|---|---|---|
| **スポットライト** | **5W** | 5W | 筒本体・ステージ照明 |
| **用途** | 照明 + 位置検知 | 照明 + 位置検知 | 赤外線センサーと連携 |

## 📐 回路構成

### ブロック図

```
[AC100V/DC24V] → [電源回路] → [24V出力]
                      ↓
              [マイコン(ESP32/Arduino)]
                      ↓
          ┌───────────┼───────────┐
          ↓           ↓           ↓
    [モータードライバ] [通信回路] [センサー入力]
          ↓           ↓
      [モーター]   [筒基板]
                  (ステレオ4極)
```

### 主要回路

#### 1. 電源回路
- AC100V → DC24V 変換（AC-DCコンバータ）
- または DC24V入力（外部電源）
- 24V → 5V/3.3V 降圧（マイコン用）
- 逆接続保護ダイオード
- 過電流保護ヒューズ

#### 2. マイコン回路
- ESP32-S3 or Arduino
- クリスタル発振子
- リセット回路
- デバッグ用UART
- GPIO保護回路

#### 3. モーター制御回路
- モータードライバIC
- PWM入力
- 電流センシング（オプション）
- 逆起電力保護

#### 4. 通信回路
- UART → ステレオ4極ジャック
- ESD保護回路（TX/RX）
- プルアップ/プルダウン抵抗
- 24V電源供給ライン

#### 5. センサー入力回路
- リミットスイッチ × 2（上限/下限）
- プルアップ抵抗
- ノイズフィルタ

## 🔌 コネクタ仕様

### 1. 筒基板接続（ステレオ4極ジャック）

| ピン | 信号 | 備考 |
|---|---|---|
| Tip | TX | ウィンチ → 筒 |
| Ring1 | RX | 筒 → ウィンチ |
| Ring2 | 24V | 電源供給 |
| Sleeve | GND | 共通グランド |

### 2. 電源入力

| ピン | 信号 | 備考 |
|---|---|---|
| 1 | AC100V/DC24V+ | 電源入力 |
| 2 | GND | グランド |

### 3. モーター接続

| ピン | 信号 | 備考 |
|---|---|---|
| TBD | モーター信号 | モーター種別に応じて |

## 📏 物理仕様

| 項目 | 仕様 | 備考 |
|---|---|---|
| **基板サイズ** | TBD mm × TBD mm | 設置スペースに応じて |
| **取付方法** | ネジ止め or DINレール | 天井設置を考慮 |
| **防水性** | IP20以上 | 屋内使用 |
| **動作温度** | 0℃〜40℃ | 会場環境 |

## 🧪 テスト項目

### 1. 電源テスト
- [ ] 入力電圧範囲テスト
- [ ] 出力電圧安定性テスト
- [ ] 過電流保護動作確認
- [ ] 逆接続保護動作確認

### 2. モーター制御テスト
- [ ] モーター駆動確認
- [ ] 速度制御精度テスト
- [ ] トルク測定
- [ ] 連続運転テスト（1時間）

### 3. 通信テスト
- [ ] 筒基板との通信確認
- [ ] データ送受信エラーレート測定
- [ ] ケーブル断線検知テスト
- [ ] ノイズ耐性テスト

### 4. センサーテスト
- [ ] リミットスイッチ動作確認
- [ ] エンコーダー精度テスト（オプション）
- [ ] 電流センサー精度テスト（オプション）

### 5. 安全機能テスト
- [ ] 緊急停止ボタン動作確認
- [ ] ソフトウェアリミット動作確認
- [ ] ウォッチドッグタイマー動作確認

### 6. 耐久テスト
- [ ] 連続昇降テスト（24時間）
- [ ] 温度上昇測定
- [ ] 長期動作安定性テスト（1週間）

## 📝 設計メモ

### V1の構造（参考）
- **基板構成**: 7枚構成（複雑）
- **スリップリング**: 回転給電・通信用
- **電源変換**: AC100V → DC24V/5V 内蔵
- **通信方式**: RS485（ノイズ耐性）
- **モーター**: 低騒音ステッピングモーター
- **非常ブレーキ**: ソレノイド式

### V2への主要改良点（優先度順）

#### 🔴 優先度: Critical
- [ ] **基板統合**: 7枚 → **2-3枚に削減**
  - 組立工数削減、故障箇所特定容易化
  - モジュール化による段階的製造可能

- [ ] **通信簡素化**: RS485 → **UART**
  - 配線削減（4線: GND, 24V, TX, RX）
  - ESD保護回路必須

- [ ] **スリップリング簡素化**
  - 接点数最小化（電源 + 通信のみ）
  - 長寿命材質選定

#### 🟡 優先度: High
- [ ] **電源統一検討**: AC100V → **DC24V入力**のみ
  - AC-DC変換回路削除でコスト削減
  - 安全性向上（低電圧化）

- [ ] **ソレノイドブレーキ代替**
  - 電気的ブレーキ方式の検討
  - コスト・重量削減

- [ ] **コネクタ脱落防止強化**
  - ステレオ4極ジャック固定機構
  - 磁石コネクタ採用範囲拡大

#### 🟢 優先度: Medium
- [ ] エンコーダー追加検討（位置精度向上）
- [ ] 電流センサー追加（予防保全）
- [ ] 基板サイズ最適化

### 検討事項
- [x] **モーター種別**: ステッピングモーター（V1実績継承）
- [x] **親機通信方式**: Wi-Fi（V1実績継承、128台制御可能）
- [ ] エンコーダーの必要性: オプション検討
- [ ] 筒重量の最終確定: 評価ボードテスト後
- [x] ケーブル長: 最大3メートル（V1実績）

### リスク & 対策
| リスク | 影響 | V1での対策 | V2での対策 |
|---|---|---|---|
| **ケーブル断線** | 通信/給電断 | 3メートル制限 | **耐久テスト1ヶ月**（評価ボード） |
| **スリップリング摩耗** | 接触不良 | 定期メンテナンス | 長寿命材質、接点数削減 |
| **電源ノイズ** | 通信エラー | RS485採用 | **ESD保護回路必須**（UART） |
| **モーター過熱** | 動作停止 | 低騒音モーター | 温度監視オプション検討 |
| **7枚基板複雑性** | メンテナンス困難 | - | **2-3枚に統合** |

### V1で成功した点（V2で継承）
- ✅ Wi-Fi通信（最大128台制御）
- ✅ 低騒音ステッピングモーター
- ✅ 赤外線式位置検知センサー
- ✅ 5Wスポットライト
- ✅ ダクトレール固定方式
- ✅ スリップリング回転給電（簡素化して継承）

## 🔗 関連ドキュメント

### プロジェクトドキュメント
- [evaluation-board-design.md](../tasks/evaluation-board-design.md) - 筒評価ボード仕様（10/24発注締切）
- [v1-analysis.md](../../notes/v1-analysis.md) - V1システム詳細分析
- [arduino-pullup-resistor-lecture.md](../../notes/arduino-pullup-resistor-lecture.md) - プルアップ抵抗の説明

### V1参考資料
- V1 EasyEDAファイル: [https://pro.easyeda.com/editor#id=91112fbff8f44189b064c06750374ec7](https://pro.easyeda.com/editor#id=91112fbff8f44189b064c06750374ec7)
- 画像資料: fu_summary.png, fu_winch.png, fu_tube.png

## 📅 更新履歴

| 日付 | バージョン | 変更内容 | 担当 |
|---|---|---|---|
| 2025-10-16 | V2.0 Draft | 初版作成 | kyopan |

---

## ✅ レビュー承認

| 役割 | 氏名 | 日付 | 署名 |
|---|---|---|---|
| 設計 | kyopan | | |
| レビュー | Hirano | | |
| 承認 | | | |

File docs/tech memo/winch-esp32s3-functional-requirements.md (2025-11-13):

# Winch ESP32-S3 機能要件整理

**プロジェクト**: FU@ComoNe (Fragmentations of Unity @ Common Nexus)
**作成日**: 2025-10-17
**目的**: ESP32-S3ピンアサイン確定のための機能要件明確化

---

## 📋 目的

基板発注前に、ファームウェアの機能要件とハードウェア設計の整合性を確保し、ESP32-S3のピンアサインを確定する。

**現状**:
- メカ完成
- PCB回路図作成済み（WPCBB）
- ファームウェアv9実装済み

**必要作業**:
1. 機能要件の整理（このドキュメント）
2. PCB回路図との照合
3. ピンアサイン確定
4. ファームウェア修正

---

## 🎯 システム概要

### U1（ESP32-S3）の役割

```
┌─────────────────────────────────────────┐
│         インターネット/MQTTブローカー      │
└──────────────┬──────────────────────────┘
               │ WiFi
    ┌──────────▼──────────┐
    │   U1 (ESP32-S3)     │ ← メインコントローラー
    │  - WiFi/MQTT        │
    │  - I2C Master       │
    │  - UART Master      │
    └─┬─────────────────┬─┘
      │ I2C             │ UART (Serial1)
      │                 │
   ┌──▼───┐         ┌──▼───────┐
   │  U2  │         │    U3    │
   │ウィンチ│         │ LED制御  │
   │モーター│         │姿勢センサー│
   └──────┘         └──────────┘
```

### 主要機能
1. **WiFi/MQTT通信**: クラウドから制御コマンド受信
2. **I2C通信**: U2（ウィンチモーター）制御
3. **UART通信**: U3（LED制御）へデータ送信
4. **LED制御**: システムステータス表示（オンボードNeoPixel）

---

## 🔌 必須ピン機能要件

### 1. WiFi/MQTT通信

| 機能 | 要件 | GPIO制約 | 備考 |
|---|---|---|---|
| **WiFi** | ESP32-S3内蔵 | なし | 追加ピン不要 |
| **MQTT** | ソフトウェア実装 | なし | WiFi経由 |

**実装箇所**: `mqttClient.cpp`

**MQTTトピック**:
- サブスクライブ: `<MAC>/idxy`, `cl/<ID>`, `ps/<ID>`, `dl/<ID>`, `at/<ID>`, `spark`, `ota`, `reboot`
- パブリッシュ: `status/<ID>`, `log/<ID>`

---

### 2. I2C通信（U1 → U2）

| 項目 | 仕様 | GPIO制約 |
|---|---|---|
| **バスアドレス** | 0x08 (U2_SLAVE_ADDRESS) | - |
| **速度** | 100kHz | - |
| **SDA** | GPIO 8 | I2C対応GPIO必須 |
| **SCL** | GPIO 9 | I2C対応GPIO必須 |
| **プルアップ抵抗** | 4.7kΩ推奨 | 外部抵抗必要 |

**実装箇所**: `main.cpp:11-12`, `mqttClient.cpp`

**コマンド一覧**:
| コマンド | バイト構成 | 機能 |
|---|---|---|
| `'Z'` | `'Z' + LSB + MSB` | 垂直位置(mm)、天井基準 |
| `'L'` | `'L' + level` | ダウンライト輝度(0-255) |
| `'I'` | `'I' + deviceId` | デバイスID通知 |
| `'S'` | `'S' + LSB + MSB` | Spark秒数 |
| `'H'` | 読み取り専用 | ホーミング状態(0=進行中, 1=完了) |

**PCB回路図確認**:
- ✅ TO WPCBMS コネクタ: TX=8, RX=9, SW=10
- ⚠️ TX/RXラベルがI2C SDA/SCLと一致するか確認必要

---

### 3. UART通信（U1 → U3）

| 項目 | 仕様 | GPIO制約 |
|---|---|---|
| **ボーレート** | 38400 baud | - |
| **データビット** | 8 | - |
| **パリティ** | なし | - |
| **ストップビット** | 1 | - |
| **TX** | GPIO 18 | UART対応GPIO必須 |
| **RX** | GPIO 17 | UART対応GPIO必須（未使用） |

**実装箇所**: `main.cpp:352`

**コマンドフォーマット**:
```
統合データパケット:
DATA,F,<f_r>,<f_g>,<f_b>,R,<r_r>,<r_g>,<r_b>,P,<pitch>,<yaw>,B,<brightness>,H,<enc_h>\n

Sparkコマンド:
SPARK,<秒数>\n

クリアコマンド:
C\n
```

**PCB回路図確認**:
- ✅ TO WPCBMS コネクタ: 24V, GND, NC:7, TX:8, RX:9, SW:10
- ⚠️ H2ヘッダー: GND, TX, RX の配線確認必要

---

### 4. オンボードLED（NeoPixel）

| 項目 | 仕様 | GPIO制約 |
|---|---|---|
| **GPIO** | GPIO 48 | NeoPixel対応GPIO |
| **個数** | 1個 | - |
| **タイプ** | NEO_GRB + NEO_KHZ800 | - |

**実装箇所**: `main.cpp:10`

**用途**: システムステータス表示
- 起動時: 赤色点灯
- WiFi接続中: 青色点滅
- MQTT接続済み: 緑色
- エラー: 赤色点滅

**PCB回路図確認**:
- ✅ ESP32-S3-DevKitC-1ボードのオンボードLED（GPIO48内蔵）

---

### 5. LED Driver制御（外部LED用）

| 項目 | 仕様 | GPIO制約 |
|---|---|---|
| **制御信号** | LED_C, LED_PWM | PWM対応GPIO推奨 |
| **ドライバIC** | TPS92200DDCR | - |
| **出力** | LED_A (24V駆動) | - |

**実装箇所**: ファームウェア内で未実装（U3経由でLED制御）

**PCB回路図確認**:
- ✅ LED_C, LED_PWMがESP32-S3に接続されている
- ⚠️ GPIO番号の確認必要

---

### 6. ステッパーモーター制御（TMC2209経由）

| 項目 | 仕様 | GPIO制約 |
|---|---|---|
| **制御信号** | TMC2209_EN, MS1, MS2, STEP, DIR, RX | GPIO必須 |
| **ドライバIC** | TMC2209 | UART通信可能 |
| **接続** | STEPPER_H1, STEPPER_H2コネクタ | - |

**実装箇所**: U2基板経由（I2C制御）、U1からは直接制御なし

**PCB回路図確認**:
- ✅ TMC2209信号線はESP32-S3に接続されている
- ⚠️ GPIO番号の確認必要
- ⚠️ U2との役割分担確認必要（U1から直接制御するか、U2経由か）

---

### 7. 電磁ブレーキ制御

| 項目 | 仕様 | GPIO制約 |
|---|---|---|
| **制御信号** | SOLENOID | GPIO必須 |
| **回路** | Q1 (20N06), Q2 (NPN), R6 (100kΩ) | - |
| **安全機能** | プルダウン抵抗でフェイルセーフ | - |

**実装箇所**: ファームウェア内で未実装（U2経由で制御可能性）

**PCB回路図確認**:
- ✅ SOLENOID信号線がESP32-S3に接続されている
- ⚠️ GPIO番号の確認必要
- ⚠️ ファームウェアでの実装必要性を確認

---

### 8. 電源系統

| 項目 | 仕様 | 備考 |
|---|---|---|
| **24V入力** | TO WPCBMS, Fuse経由 | 全体電源 |
| **5V DCDC** | TPS54202DDC (U1) | ESP32-S3用 |
| **5V BX-PM2.54-1-22PY** | H2ヘッダー | ESP32-S3ボード供給 |
| **電流容量** | TBD | 負荷計算必要 |

**PCB回路図確認**:
- ✅ 5V電源レギュレーター配置確認
- ⚠️ 電流容量がESP32-S3（最大500mA）+ 周辺回路に十分か確認

---

## 📊 GPIO使用状況サマリー

### 現在確定済みピン（ファームウェアv9ベース）

| GPIO | 機能 | 接続先 | 実装箇所 | Status |
|---|---|---|---|---|
| **48** | NeoPixel RGB LED | オンボード | main.cpp:10 | ✅ 確定 |
| **8** | I2C SDA | U2 (ウィンチ) | main.cpp:11 | ✅ 確定 |
| **9** | I2C SCL | U2 (ウィンチ) | main.cpp:12 | ✅ 確定 |
| **17** | UART RX (Serial1) | U3 (LED) | main.cpp:352 | ✅ 確定（未使用） |
| **18** | UART TX (Serial1) | U3 (LED) | main.cpp:352 | ✅ 確定 |

### PCB回路図から判明した追加接続

| 信号名 | 推定機能 | PCB接続先 | GPIO（未確定） | 優先度 |
|---|---|---|---|---|
| **LED_C** | LED制御 | TPS92200DDCR | TBD | Medium |
| **LED_PWM** | LED PWM | TPS92200DDCR | TBD | Medium |
| **TMC2209_EN** | ステッパー有効 | TMC2209 | TBD | High（U2経由なら不要） |
| **TMC2209_MS1** | マイクロステップ | TMC2209 | TBD | Low（U2経由なら不要） |
| **TMC2209_MS2** | マイクロステップ | TMC2209 | TBD | Low（U2経由なら不要） |
| **TMC2209_STEP** | ステップパルス | TMC2209 | TBD | High（U2経由なら不要） |
| **TMC2209_DIR** | 回転方向 | TMC2209 | TBD | High（U2経由なら不要） |
| **TMC2209_RX** | UART RX | TMC2209 | TBD | Medium（診断機能） |
| **SOLENOID** | 電磁ブレーキ | Q2 Base | TBD | High |

### 未使用GPIO（拡張用予約）

ESP32-S3で使用可能なGPIO:
- GPIO 0-7, 10-16, 19-21, 35-42, 45-47
- 内部使用（使用禁止）: GPIO 26-37（SPI Flash/PSRAM）

---

## 🔍 PCB回路図の詳細確認項目

### 1. TO WPCBMS コネクタ（左上）

**ピン配置（上から）**:
1. 24V
2. 24V
3. 24V
4. GND
5. GND
6. GND
7. NC (No Connect)?
8. TX（I2C SDA?）
9. RX（I2C SCL?）
10. SW

**確認事項**:
- [ ] TX/RXがI2C SDA/SCLと一致するか
- [ ] SWの用途（プルアップスイッチ?）
- [ ] NCピンの実際の接続

### 2. H2ヘッダー（5V DCDC出力）

**ピン配置**:
- 22 (GND)
- 21 (TX)
- 20 (RX)
- ... (以下続く)

**確認事項**:
- [ ] GND, TX, RXの接続先確認
- [ ] 5V供給ピンの位置確認

### 3. TMC2209周辺

**接続信号**:
- TMC2209_EN, MS1, MS2, STEP, DIR, RX
- STEPPER_H1 (M_BLK, M_GRN, M_RED, M_BLU)
- STEPPER_H2 (配線確認必要)

**確認事項**:
- [ ] TMC2209制御がU1から直接か、U2経由か
- [ ] ステッパー電源ラインのトレース幅（40mil確認済み）

### 4. LED Driver周辺

**接続信号**:
- LED_C, LED_PWM → TPS92200DDCR → LED_A

**確認事項**:
- [ ] LED_C, LED_PWMのGPIO番号
- [ ] LED制御の実装必要性（U3経由なら不要）

### 5. 電磁ブレーキ回路

**回路構成**:
- SOLENOID → R8 (10kΩ) → Q2 Base
- R6 (100kΩ) プルダウン → Q2 Base → GND
- Q2 Collector → Q1 Gate
- Q1 (20N06) → S_DRN

**確認事項**:
- [ ] SOLENOID信号のGPIO番号
- [ ] ファームウェアでの制御実装必要性

---

## ✅ 次のアクション

### Phase 1: PCB回路図の精密確認

1. **EasyEDA/KiCadファイルを開く**
   - 各信号線のGPIO番号を追跡
   - ネットリストを確認

2. **接続先の特定**
   - TO WPCBMS コネクタの各ピン → ESP32-S3 GPIO
   - H2ヘッダーの各ピン → ESP32-S3 GPIO
   - TMC2209信号 → ESP32-S3 GPIO または U2経由
   - SOLENOID → ESP32-S3 GPIO

3. **ドキュメント更新**
   - [winch-u1-esp32s3-pinout.md](winch-u1-esp32s3-pinout.md) に確定ピンを記載

### Phase 2: ファームウェア機能実装確認

1. **TMC2209制御**
   - U1から直接制御 → GPIO割り当て必要
   - U2経由で制御 → I2C経由で制御、追加GPIO不要

2. **電磁ブレーキ制御**
   - フェイルセーフ確認（プルダウン抵抗により、起動時ブレーキON）
   - ファームウェアでの制御実装

3. **LED Driver制御**
   - 外部LED必要性の確認
   - U3経由で十分ならGPIO不要

### Phase 3: ピンアサイン確定

1. **winch-u1-esp32s3-pinout.md 更新**
   - 全GPIO機能の最終決定
   - 未使用GPIOの予約用途決定

2. **ファームウェア修正**
   - main.cpp, mqttClient.cpp のGPIO定義更新
   - 新機能の実装（必要に応じて）

3. **ビルド&テスト**
   - PlatformIOでビルド
   - I2C/UART通信テスト

### Phase 4: 基板発注

- **締切**: 2025-10-24
- **発注先**: JLCPCB
- **仕様確認**: トレース幅、銅箔厚、部品実装

---

## 🔗 関連ドキュメント

| ドキュメント | 用途 |
|---|---|
| [winch-u1-esp32s3-pinout.md](winch-u1-esp32s3-pinout.md) | ピンアサイン仕様（更新対象） |
| [U1_FIRMWARE_OVERVIEW.md](../../firmware/Winch/U1/U1_FIRMWARE_OVERVIEW.md) | ファームウェア完全概要 |
| [winch-circuit-design-v2.md](winch-circuit-design-v2.md) | Winch V2回路設計仕様 |
| [winch-electromagnetic-brake-circuit.md](winch-electromagnetic-brake-circuit.md) | 電磁ブレーキ回路仕様 |
| [winch-stepper-trace-width-analysis.md](../../notes/winch-stepper-trace-width-analysis.md) | ステッパートレース幅解析 |

---

## 📝 メモ

### PCB回路図ラベルの疑問点

1. **TX/RX vs SDA/SCL**:
   - TO WPCBMSコネクタのTX/RXラベル
   - ファームウェアではI2C SDA/SCL（GPIO8/9）
   - ラベルミス or UART/I2C兼用設計?

2. **TMC2209制御主体**:
   - U1から直接制御（GPIO必要）
   - U2が独立制御（I2C経由でコマンド送信）
   - 現状ファームウェアはU2経由前提

3. **LED Driver必要性**:
   - 外部LEDを直接制御する設計?
   - U3経由で十分なら未使用でOK

これらの疑問点を解消するため、PCB回路図の精密確認が必要です。

---

**優先度**: 🔴 最優先（2025-10-24発注締切）
**次のステップ**: PCB回路図をEasyEDAで開いて各信号線を追跡

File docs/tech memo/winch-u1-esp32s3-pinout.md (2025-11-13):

# Winch U1 ESP32-S3 ピンアサイン仕様 V2

**プロジェクト**: FU@ComoNe (Fragmentations of Unity @ Common Nexus)
**ボード**: ESP32-S3-DevKitC-1
**アーキテクチャ**: デュアルコア（V2）
**GPIO確定日**: 2025-10-17
**最終更新**: 2025-10-17

---

## 📋 V2アーキテクチャ概要

### V1からの主要変更点

**V1（旧）**:
- U1（ESP32-S3）: WiFi/MQTT制御
- U2（独立マイコン）: モーター制御
- U3（独立マイコン）: LED/姿勢制御

**V2（新）**:
- **U1（ESP32-S3デュアルコア）のみ**:
  - Core 0: WiFi/MQTT通信
  - Core 1: モーター制御（TMC2209）、LED制御
- U2は廃止
- U3は吊り筒側で独立制御

### システム構成

```mermaid
graph TB
    subgraph Internet["☁️ インターネット"]
        MQTT[MQTTブローカー]
    end

    subgraph WinchBox["📦 Winchボックス (天井固定)"]
        subgraph U1["🖥️ U1 - ESP32-S3 DevKitC-1"]
            subgraph Core0["Core 0: Protocol"]
                WiFi[WiFi通信]
                MQTTClient[MQTT Client]
                SysCtrl[システム管理]
            end

            subgraph Core1["Core 1: Application"]
                UART1[UART1: 筒制御]
                UART2[UART2: TMC2209]
                LED_Ctrl[LED Driver制御]
                Brake[電磁ブレーキ制御]
            end
        end

        LED_3W[3W LED<br/>Winch照明]
        TMC2209[TMC2209<br/>ステッパードライバ]
        EMBrake[電磁ブレーキ]
        StepperMotor[ステッパーモーター<br/>Nema 17 + ブレーキ]
    end

    subgraph Cable["🔌 電源通信ケーブル"]
        Wire[24V + GND + TX + RX]
    end

    subgraph Tube["🎨 筒 (吊り下げ)"]
        U3[U3マイコン]
        NeoPixel[NeoPixel LED]
        IMU[姿勢センサー]
    end

    MQTT -.WiFi.-> WiFi
    WiFi --> MQTTClient
    MQTTClient --> SysCtrl

    SysCtrl -.制御指令.-> UART1
    SysCtrl -.制御指令.-> UART2
    SysCtrl -.制御指令.-> LED_Ctrl
    SysCtrl -.制御指令.-> Brake

    UART1 -->|TX/RX| Wire
    Wire -->|TX/RX| U3
    Wire -.24V/GND給電.-> U3

    UART2 -->|TX/RX| TMC2209
    TMC2209 -->|STEP/DIR/EN| StepperMotor

    LED_Ctrl -->|PWM| LED_3W
    Brake -->|SOLENOID| EMBrake
    EMBrake -.機械的結合.-> StepperMotor

    U3 --> NeoPixel
    U3 --> IMU

    style Core0 fill:#e1f5fe
    style Core1 fill:#f3e5f5
    style U1 fill:#fff3e0
    style WinchBox fill:#ffe0b2
    style Cable fill:#ffccbc
    style Tube fill:#c8e6c9
```

---

## 🔌 ピンアサイン一覧

### 確定済みピン

| GPIO | 機能 | 接続先 | 制約 | 備考 |
|---|---|---|---|---|
| **48** | NeoPixel RGB LED | オンボード | - | システムステータス表示 |
| **8** | UART1 TX | TO WPCBMS (筒側) | Serial1 | 電源通信ケーブル経由、左側上部 |
| **9** | UART1 RX | TO WPCBMS (筒側) | Serial1 | 電源通信ケーブル経由、左側上部 |
| **17** | UART2 TX | TMC2209 | Serial2 | TMC2209制御用、STEPPER_H2近く |
| **18** | UART2 RX | TMC2209 | Serial2 | TMC2209診断用、STEPPER_H2近く |
| **10** | TMC2209_EN | TMC2209 | GPIO | ステッパー有効化、連続配置 |
| **11** | TMC2209_MS1 | TMC2209 | GPIO | マイクロステップ設定、連続配置 |
| **12** | TMC2209_MS2 | TMC2209 | GPIO | マイクロステップ設定、連続配置 |
| **13** | TMC2209_STEP | TMC2209 | GPIO | ステップパルス、連続配置 |
| **14** | TMC2209_DIR | TMC2209 | GPIO | 回転方向、連続配置 |
| **38** | LED_C | TPS92200DDCR | GPIO | LED制御信号（Winch照明）、右側 |
| **35** | LED_PWM | TPS92200DDCR | PWM | LED輝度PWM（Winch 3W LED）、右側 |
| **2** | SOLENOID | 電磁ブレーキ回路 | GPIO | ブレーキ制御、左側下部 |

---

## 📡 通信仕様

### UART1通信（U1 → U3 筒側）

**物理層**:
- **ポート**: Serial1
- **TX**: GPIO 8
- **RX**: GPIO 9
- **ボーレート**: 38400 baud
- **データビット**: 8
- **パリティ**: なし
- **ストップビット**: 1
- **伝送路**: TO WPCBMS経由、電源通信ケーブル（24V, GND, TX, RX）

**筒側構成**:
- U3マイコン（筒内部）
- NeoPixel LED（U3制御）
- 姿勢センサー（IMU, U3読み取り）

**コマンドフォーマット** (V1互換):
```
統合データパケット:
DATA,F,<f_r>,<f_g>,<f_b>,R,<r_r>,<r_g>,<r_b>,P,<pitch>,<yaw>,B,<brightness>,H,<enc_h>\n

Sparkコマンド:
SPARK,<秒数>\n

クリアコマンド:
C\n
```

**注意**: U3は筒内でNeoPixelを直接制御し、UART経由でコマンドを受信する。

---

### UART2通信（U1 → TMC2209）

**物理層**:
- **ポート**: Serial2
- **TX**: GPIO 17
- **RX**: GPIO 18
- **ボーレート**: 115200 baud（TMC2209標準）
- **データビット**: 8
- **パリティ**: なし
- **ストップビット**: 1

**用途**:
- TMC2209の詳細設定（電流制限、StealthChop/SpreadCycle切替）
- 診断情報読み取り（温度、ストール検出）
- レジスタ読み書き

**コマンド例**（TMCUARTプロトコル）:
```cpp
// 電流設定（RMS電流）
TMC2209.tmc_writeRegister(TMC2209_IHOLD_IRUN, 0x00051010);

// StealthChop有効化
TMC2209.tmc_writeRegister(TMC2209_GCONF, 0x00000004);

// ストール検出閾値設定
TMC2209.tmc_writeRegister(TMC2209_SGTHRS, 100);
```

---

## 🎛️ ステッパーモーター制御（TMC2209）

### ピンアサイン（確定）

| 信号名 | GPIO | 機能 | 配置理由 |
|---|---|---|---|
| **TMC2209_EN** | GPIO 10 | イネーブル（LOW=有効） | 連続配置開始、STEPPER_H2近接 |
| **TMC2209_MS1** | GPIO 11 | マイクロステップ設定 | 連続配置、配線簡素化 |
| **TMC2209_MS2** | GPIO 12 | マイクロステップ設定 | 連続配置、配線簡素化 |
| **TMC2209_STEP** | GPIO 13 | ステップパルス | 連続配置、配線簡素化 |
| **TMC2209_DIR** | GPIO 14 | 方向制御（HIGH=CW） | 連続配置、配線簡素化 |
| **UART2_TX** | GPIO 17 | TMC2209 UART送信（Serial2） | STEPPER_H2近接 |
| **UART2_RX** | GPIO 18 | TMC2209 UART受信（Serial2） | STEPPER_H2近接 |

### ステッパー仕様

| 項目 | 仕様 |
|---|---|
| **型番** | Nema 17 - 17HS24-2004D-B070 |
| **定格電流** | 2.0A/相 |
| **電圧** | 24V |
| **トルク** | 0.72Nm (101.96oz.in) |
| **特徴** | 電磁ブレーキ付き |

### マイクロステップ設定

| MS1 | MS2 | ステップ分解能 |
|-----|-----|---|
| LOW | LOW | 1/8 |
| HIGH | LOW | 1/16 |
| LOW | HIGH | 1/32 |
| HIGH | HIGH | 1/64 |

### 制御コード例

```cpp
// GPIO定義
#define TMC2209_EN 10
#define TMC2209_MS1 11
#define TMC2209_MS2 12
#define TMC2209_STEP 13
#define TMC2209_DIR 14

// Core 1: モーター制御タスク
void motorControlTask(void* parameter) {
  pinMode(TMC2209_EN, OUTPUT);
  pinMode(TMC2209_STEP, OUTPUT);
  pinMode(TMC2209_DIR, OUTPUT);
  pinMode(TMC2209_MS1, OUTPUT);
  pinMode(TMC2209_MS2, OUTPUT);

  // 1/16マイクロステップ設定
  digitalWrite(TMC2209_MS1, HIGH);
  digitalWrite(TMC2209_MS2, LOW);

  // モーター有効化
  digitalWrite(TMC2209_EN, LOW);

  while(1) {
    // ステップパルス生成
    digitalWrite(TMC2209_STEP, HIGH);
    delayMicroseconds(100);
    digitalWrite(TMC2209_STEP, LOW);
    delayMicroseconds(100);
  }
}
```

---

## 💡 LED Driver制御（3W LED用）

### ピンアサイン（確定）

| 信号名 | GPIO | 機能 | 配置理由 |
|---|---|---|---|
| **LED_C** | GPIO 38 | LED制御信号 | TPS92200DDCR近接、右側配置 |
| **LED_PWM** | GPIO 35 | LED輝度PWM | TPS92200DDCR近接、PWM対応 |

### LED仕様

| 項目 | 仕様 |
|---|---|
| **タイプ** | 既製品3W LED |
| **ドライバIC** | TPS92200DDCR |
| **電源** | 24V |
| **出力** | LED_A |
| **制御** | LED_C（ON/OFF）、LED_PWM（輝度） |

### 制御コード例

```cpp
// GPIO定義
#define LED_C 38
#define LED_PWM 35

// LED PWM設定
const int LED_PWM_CHANNEL = 0;
const int LED_PWM_FREQ = 5000;  // 5kHz
const int LED_PWM_RESOLUTION = 8;  // 8bit (0-255)

void setupLEDDriver() {
  pinMode(LED_C, OUTPUT);
  ledcSetup(LED_PWM_CHANNEL, LED_PWM_FREQ, LED_PWM_RESOLUTION);
  ledcAttachPin(LED_PWM, LED_PWM_CHANNEL);
}

void setLEDBrightness(uint8_t brightness) {
  digitalWrite(LED_C, HIGH);  // LED有効化
  ledcWrite(LED_PWM_CHANNEL, brightness);  // 0-255
}
```

---

## 🛑 電磁ブレーキ制御

### ピンアサイン（確定）

| 信号名 | GPIO | 機能 | 配置理由 |
|---|---|---|---|
| **SOLENOID** | GPIO 2 | ブレーキ制御 | Q2ブレーキ回路近接、左側下部 |

### 回路構成

```
SOLENOID ─── R8 (10kΩ) ─── Q2 Base
                             |
                        R6 (100kΩ) プルダウン
                             |
                            GND

Q2 Collector → Q1 Gate
Q1 (20N06 MOSFET) → S_DRN → 電磁ブレーキ
```

### 動作仕様

| SOLENOID状態 | Q2状態 | Q1状態 | ブレーキ状態 |
|---|---|---|---|
| Hi-Z（起動時） | OFF | ON | **ブレーキON（安全）** |
| LOW | OFF | ON | **ブレーキON** |
| HIGH | ON | OFF | **ブレーキOFF** |

### 制御コード例

```cpp
// GPIO定義
#define SOLENOID 2

void setupBrake() {
  pinMode(SOLENOID, OUTPUT);
  digitalWrite(SOLENOID, LOW);  // 起動時ブレーキON（安全）
}

void releaseBrake() {
  digitalWrite(SOLENOID, HIGH);
  delay(50);  // 機械的遅延
}

void applyBrake() {
  digitalWrite(SOLENOID, LOW);
  delay(10);
}

void moveMotor(int steps) {
  releaseBrake();  // ブレーキ解除
  delay(100);

  // モーター制御
  for(int i = 0; i < steps; i++) {
    digitalWrite(TMC2209_STEP, HIGH);
    delayMicroseconds(100);
    digitalWrite(TMC2209_STEP, LOW);
    delayMicroseconds(100);
  }

  applyBrake();  // ブレーキ再適用
}
```

---

## ⚙️ デュアルコアタスク設計

### Core 0: Protocol Task

**役割**: WiFi/MQTT通信、システム管理

```cpp
void setup() {
  // Core 0で実行
  Serial.begin(115200);

  // WiFi/MQTT初期化
  setupWiFi();
  setupMQTT();

  // Core 1タスク起動
  xTaskCreatePinnedToCore(
    motorControlTask,   // タスク関数
    "MotorControl",     // タスク名
    10000,              // スタックサイズ
    NULL,               // パラメータ
    1,                  // 優先度
    NULL,               // タスクハンドル
    1                   // Core 1に固定
  );
}

void loop() {
  // Core 0: MQTT処理
  mqttClient.loop();
  handleMQTTCommands();
  delay(10);
}
```

### Core 1: Application Task

**役割**: モーター制御、LED制御、ブレーキ制御

```cpp
void motorControlTask(void* parameter) {
  // Core 1で実行
  setupMotor();
  setupLEDDriver();
  setupBrake();

  while(1) {
    // モーター制御
    if(targetPositionChanged) {
      moveToPosition(targetPosition);
    }

    // LED制御
    if(ledBrightnessChanged) {
      setLEDBrightness(ledBrightness);
    }

    delay(1);
  }
}
```

---

## 🔧 ファームウェア修正チェックリスト

### main.cpp

- [x] GPIO定義を更新（2025-10-17確定）
  ```cpp
  // UART1（筒側通信）
  #define UART1_TX_PIN 8
  #define UART1_RX_PIN 9

  // UART2（TMC2209通信）
  #define UART2_TX_PIN 17
  #define UART2_RX_PIN 18

  // TMC2209制御
  #define TMC2209_EN 10
  #define TMC2209_MS1 11
  #define TMC2209_MS2 12
  #define TMC2209_STEP 13
  #define TMC2209_DIR 14

  // LED Driver（Winch照明用）
  #define LED_C 38
  #define LED_PWM 35

  // 電磁ブレーキ
  #define SOLENOID 2

  // NeoPixel（システムステータス）
  #define ONBOARD_LED_PIN 48
  ```

- [ ] I2C関連コードを削除（U2廃止のため）
- [ ] デュアルコアタスク実装
  - Core 0: WiFi/MQTT
  - Core 1: TMC2209/LED/ブレーキ制御
- [ ] UART1実装（筒側通信、Serial1）
- [ ] UART2実装（TMC2209通信、Serial2）
- [ ] TMC2209制御実装（STEP/DIR/EN + UART）
- [ ] LED Driver制御実装（Winch 3W LED照明）
- [ ] 電磁ブレーキ制御実装（フェイルセーフ）

### platformio.ini

- [ ] ボード設定確認
  ```ini
  board = esp32-s3-devkitc-1
  ```

- [ ] ビルドフラグ
  ```ini
  build_flags =
    -DARDUINO_USB_MODE=1
    -DARDUINO_USB_CDC_ON_BOOT=1
    -DCORE_DEBUG_LEVEL=3
  ```

---

## 🧪 テスト計画

### 1. UART通信テスト（U1 → U3 筒側）

| # | テスト内容 | コマンド | 期待結果 |
|---|---|---|---|
| 1 | 統合パケット送信 | DATA,F,255,0,0,... | U3でLED点灯 |
| 2 | Sparkコマンド | SPARK,10\n | U3でSparkモード開始 |
| 3 | クリアコマンド | C\n | U3でクリア動作 |

### 2. TMC2209制御テスト

| # | テスト内容 | 期待結果 |
|---|---|---|
| 1 | モーター有効化 | EN=LOWでモーター通電 |
| 2 | ステップパルス | STEP信号でモーター回転 |
| 3 | 方向制御 | DIR=HIGH/LOWで正逆回転 |
| 4 | マイクロステップ | MS1/MS2で分解能変更 |

### 3. LED Driver制御テスト

| # | テスト内容 | 期待結果 |
|---|---|---|
| 1 | LED ON/OFF | LED_C=HIGHで点灯 |
| 2 | PWM輝度制御 | LED_PWM=0-255で明るさ変化 |

### 4. ブレーキ制御テスト

| # | テスト内容 | 期待結果 |
|---|---|---|
| 1 | 電源投入時 | ブレーキON（安全確認） |
| 2 | ブレーキ解除 | SOLENOID=HIGHで解除 |
| 3 | ブレーキ適用 | SOLENOID=LOWで作動 |
| 4 | モーター動作 | ブレーキ解除→回転→ブレーキ適用 |

---

## 📊 GPIO使用可能数の確認

### ESP32-S3 GPIO制約

| 分類 | GPIO番号 | 備考 |
|---|---|---|
| **使用可能** | 0-21, 35-48 | 合計35本 |
| **内部使用（禁止）** | 26-32 | SPI Flash/PSRAM |
| **Strapping Pins** | 0, 3, 45, 46 | プルアップ/ダウン注意 |
| **USB** | 19, 20 | USB使用時は不可 |
| **JTAG** | 39-42 | デバッグ使用時は不可 |
| **UART0** | 43, 44 | デバッグ用、変更非推奨 |

### 現在の使用状況

**確定済み（2025-10-17）**: 13本
- GPIO 2: SOLENOID（ブレーキ）
- GPIO 8: UART1 TX（筒側通信）
- GPIO 9: UART1 RX（筒側通信）
- GPIO 10: TMC2209_EN
- GPIO 11: TMC2209_MS1
- GPIO 12: TMC2209_MS2
- GPIO 13: TMC2209_STEP
- GPIO 14: TMC2209_DIR
- GPIO 17: UART2_TX（TMC2209）
- GPIO 18: UART2_RX（TMC2209）
- GPIO 35: LED_PWM（Winch照明）
- GPIO 38: LED_C（Winch照明）
- GPIO 48: NeoPixel（システムステータス）

**予備**: 22本 / 35本使用可能（将来拡張に十分な余裕）

---

## 📝 PCB回路図確認項目

### TO WPCBMS コネクタ

| ピン | 信号 | 接続先 | 確認 |
|---|---|---|---|
| 1-3 | 24V | 電源供給 | ✅ |
| 4-6 | GND | GND | ✅ |
| 7 | NC | - | ⚠️ 未確認 |
| 8 | TX | ESP32-S3 GPIO8 | ✅ 確定 |
| 9 | RX | ESP32-S3 GPIO9 | ✅ 確定 |
| 10 | SW | - | ⚠️ 用途確認 |

### TMC2209周辺

- [x] EN, MS1, MS2, STEP, DIR: GPIO 10-14（連続配置、2025-10-17確定）
- [x] UART2 TX/RX: GPIO 17/18（診断用、2025-10-17確定）
- [ ] PCB上の配線が確定GPIO番号と一致するか回路図で確認

### LED Driver周辺

- [x] LED_C: GPIO 38, LED_PWM: GPIO 35（2025-10-17確定）
- [ ] PCB上のTPS92200DDCR配線が確定GPIO番号と一致するか回路図で確認

### 電磁ブレーキ回路

- [x] SOLENOID: GPIO 2（2025-10-17確定）
- [x] R6 (100kΩ) プルダウン実装確認済み（fail-safe設計）

---

## ✅ 次のアクション

### ~~Phase 1: GPIO Pin Assignment~~ ✅ 完了（2025-10-17）

- ✅ PCBレイアウト解析完了
- ✅ GPIO番号確定（全13本）
- ✅ ドキュメント更新完了

**成果物**: [wpcbb-pinout-analysis.md](wpcbb-pinout-analysis.md)

### Phase 2: PCB回路図とのクロスチェック ⏩ 次のステップ

1. **EasyEDA/KiCadで回路図を開く**
2. **配線がGPIO番号と一致するか確認**:
   - [ ] TMC2209（GPIO 10-14, 17-18）→ STEPPER_H2配線
   - [ ] LED Driver（GPIO 35, 38）→ TPS92200DDCR配線
   - [ ] Brake（GPIO 2）→ Q2ブレーキ回路配線
   - [ ] TO WPCBMS（GPIO 8, 9）→ コネクタピン8/9
3. **不一致があれば回路図修正**

### Phase 3: ファームウェア実装

1. **デュアルコアタスク実装**
2. **TMC2209制御実装**（GPIO定義済み）
3. **LED Driver制御実装**（GPIO定義済み）
4. **電磁ブレーキ制御実装**（GPIO定義済み）
5. **I2C関連コード削除**（U2廃止）

### Phase 4: テスト & 基板発注

1. **ビルド&書き込み**
2. **各機能の動作確認**
3. **基板発注**（締切: 2025-10-24）

---

## 🔗 関連ドキュメント

| ドキュメント | 用途 |
|---|---|
| [wpcbb-pinout-analysis.md](wpcbb-pinout-analysis.md) | PCBレイアウト解析とGPIO最適配置（2025-10-17） |
| [winch-esp32s3-functional-requirements.md](winch-esp32s3-functional-requirements.md) | 機能要件整理 |
| [winch-circuit-design-v2.md](winch-circuit-design-v2.md) | Winch V2回路設計仕様 |
| [winch-electromagnetic-brake-circuit.md](winch-electromagnetic-brake-circuit.md) | 電磁ブレーキ回路仕様 |
| [winch-stepper-trace-width-analysis.md](../../notes/winch-stepper-trace-width-analysis.md) | ステッパートレース幅解析 |
| [ESP32-S3 Datasheet](https://www.espressif.com/sites/default/files/documentation/esp32-s3_datasheet_en.pdf) | 公式データシート |

---

**優先度**: 🔴 最優先（2025-10-24発注締切）

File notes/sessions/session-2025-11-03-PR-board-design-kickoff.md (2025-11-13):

# セッション記録: PR基板設計キックオフ

**日付**: 2025-11-03
**参加者**: kyopan, CIC
**目的**: PR基板（Pitch Ring）V2の詳細設計開始

---

## 📊 セッション概要

FU@ComoNeプロジェクトの筒本体V2実装において、PR基板（Pitch Ring）の詳細設計とWBS作成を実施。

---

## 🎯 達成事項

### 1. 構造理解の明確化

**確定した構造:**
```
ウィンチケーブル
  ↓
HR (Horizontal Ring) = FR (Flat Ring)
  - 水平固定基板
  - ESP32-S3 #1, #2搭載
  - 24V→5V DCDC
  - YAW BLDC（真下）、Pitch BLDC
  ↓ Pitch軸±60°回転
PR (Pitch Ring)
  - リング状基板
  - 真鍮線接続点×12
  - GR/CR支持構造
  ↓ 真鍮線接続
GR (GridEye Ring) + CR (Compass Ring)
  - 評価ボード流用（到着待ち）
```

### 2. 配線仕様の確定

**真鍮線12点の信号定義:**
- **PRF（前面6点）**: W2_3, W4_5, SDA0, SCL0, 5V, GND
- **PRB（背面6点）**: W6, SDA1, SCL1, W4_5, 5V, GND

**ESP32-S3役割分担:**
- **S3 #1**: ウィンチ通信 + LED/Grid-EYE/GY-85制御
- **S3 #2**: Pitch/YAWモーター + エンコーダー制御

### 3. エンコーダー配置の明確化

- **Pitchエンコーダー**: AS5600（PB基板、HRに垂直取り付け）
- **YAWエンコーダー**: AS5600（CR基板）
- **DIRエンコーダー**: AS5600（ミニプラグメス、コンパス代替）

### 4. 設計方針の確定

| 項目 | 確定内容 |
|---|---|
| **設計担当** | kyopan |
| **設計ツール** | EasyEDA |
| **PCB厚さ** | 1.6mm |
| **I2Cプルアップ** | ESP32-S3内部プルアップ使用 |
| **真鍮線接続** | 治具作成して半田付け |
| **評価PR到着** | 3日後（11/6） |

---

## 📄 作成ドキュメント

### 1. [tube-body-v2-implementation-plan.md](../../docs/tube-body-v2/tube-body-v2-implementation-plan.md)
- 筒本体V2全体の実装計画
- V1からV2への変更点整理
- ハードウェア要件、回路構成、テスト項目

### 2. [tube-body-v2-structure-understanding.md](../../docs/tube-body-v2/tube-body-v2-structure-understanding.md)
- kyopanの説明に基づく構造理解の確認ドキュメント
- 不明点の洗い出し
- Mermaid図による可視化

### 3. [PR-board-design-specification.md](../../docs/tube-body-v2/PR-board-design-specification.md)
- PR基板の詳細設計仕様書
- 配線図からの真鍮線12点の信号定義
- 機械的・電気的要件
- 評価PR vs 本番PRの差分

### 4. [PR-board-WBS.md](../../docs/tube-body-v2/PR-board-WBS.md)
- PR基板設計のWork Breakdown Structure
- 7フェーズ、46タスクの詳細計画
- ガントチャート、リスク管理、マイルストーン

### 5. [HR-mechanical-dimensions.md](../../docs/tube-body-v2/HR-mechanical-dimensions.md)
- HR基板の機械寸法設計ワークシート
- 寸法検討の手順
- 確認が必要な部品仕様リスト

### 6. [evaluation-PR-verification-plan.md](../../docs/tube-body-v2/evaluation-PR-verification-plan.md)
- 評価PR基板の検証計画（11/6-11/10）
- 5つの検証項目（LED、耐久性、通信、電源、真鍮線）
- 検証スケジュールと成果物

---

## 🔍 キーインサイト

### 1. HR = FRの用語統一
- V1企画書では「FR (Flat Ring)」
- V2配線図では「HR (Horizontal Ring)」
- 同一基板を指す → 以後HRで統一

### 2. PRリング幅の課題
- HR外径70mm、PRリング外径74mmと仮定すると、リング幅1mm
- 真鍮線×12の配置が困難な可能性
- HR外径を小さくしてPRリング幅を確保する検討必要

### 3. 評価PRの役割明確化
- スリップリング・モーター・HRが無い簡易版
- 通信・LED・耐久性テスト専用
- 本番PR設計の検証データ収集が目的

### 4. 設計の依存関係
```
HR機械寸法確定
  ↓
PR外径・内径決定
  ↓
PRリング幅確定
  ↓
真鍮線配置設計
  ↓
回路図作成
  ↓
PCBレイアウト
```

---

## ⚠️ 未確認事項・リスク

### 機械設計（作成中）
- [ ] PR基板外径・内径寸法
- [ ] PRリング幅（真鍮線×12配置可能性）
- [ ] Pitch軸機構の詳細
- [ ] 取り付け穴位置・径

### 部品仕様（確認必要）
- [ ] スリップリング直径・高さ
- [ ] YAW BLDC直径・高さ
- [ ] Pitch BLDC直径・高さ
- [ ] ESP32-S3モジュール型番・サイズ
- [ ] DCDCモジュール型番・サイズ
- [ ] 真鍮線の線径・材質

### 設計判断（保留中）
- [ ] HR-PR間コネクタ選定
- [ ] 半田付け治具の詳細設計
- [ ] リング幅不足時の対応策

---

## 📅 次のアクションステップ

### 即座に実施（11/3-11/5）

#### kyopan
1. **HR機械寸法確定**
   - スリップリング、モーター、ESP32-S3、DCDCの仕様確認
   - HR外径・内径決定
   - PRリング幅の確保可能性検討

2. **Pitch軸機構設計**
   - 機械設計図面作成
   - ±60°回転機構の詳細設計

3. **部品選定**
   - HR-PR間コネクタ選定
   - 真鍮線仕様決定

#### CIC
- 評価PR到着待ち（11/6）
- 検証計画の準備

### 評価PR到着後（11/6-11/10）

- LED光り方確認（11/6）
- ウィンチ耐久性テスト（11/7-11/8）
- 通信チェック（11/9-11/10）
- 検証結果を本番PR設計にフィードバック

### 本番PR設計開始（11/11〜）

- 機械寸法確定後、回路図作成開始
- EasyEDAで設計
- PCBレイアウト → 発注 → 組み立て → 検証

---

## 💬 kyopanからのフィードバック

### 確定情報
- HR基板設計: kyopan担当
- 機械寸法: 作成中
- 評価PR: 3日後到着
- 検証内容: LED光り方、ウィンチ耐久性、通信チェック

### 設計方針
- I2C: 内部プルアップ使用
- 真鍮線: 治具で半田付け
- PCB: 1.6mm厚
- ツール: EasyEDA

---

## 📝 学び・改善点

### CIC自身の理解深化
- 配線図から信号経路を正確に読み取れた
- HR = FRの用語統一に気づけた
- 機械寸法とPCB設計の依存関係を整理できた

### 次回セッションへの引き継ぎ
- HR機械寸法の確定が最優先
- 評価PR検証結果を本番設計に反映する流れを確立
- 真鍮線半田付け治具の詳細設計が必要

---

## 🔗 関連ドキュメント

- [tube-body-v2-implementation-plan.md](../../docs/tube-body-v2/tube-body-v2-implementation-plan.md)
- [tube-body-v2-structure-understanding.md](../../docs/tube-body-v2/tube-body-v2-structure-understanding.md)
- [PR-board-design-specification.md](../../docs/tube-body-v2/PR-board-design-specification.md)
- [PR-board-WBS.md](../../docs/tube-body-v2/PR-board-WBS.md)
- [HR-mechanical-dimensions.md](../../docs/tube-body-v2/HR-mechanical-dimensions.md)
- [evaluation-PR-verification-plan.md](../../docs/tube-body-v2/evaluation-PR-verification-plan.md)
- [actuar-wiring-2025-10-23.png](../actuar-wiring-2025-10-23.png)

---

**記録者**: CIC
**承認**: kyopan

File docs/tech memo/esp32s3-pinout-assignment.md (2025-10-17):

# ESP32-S3 DevKitC-1 ピンアサイン確定版

**プロジェクト**: FU@ComoNe (Fragmentations of Unity @ Common Nexus)
**ボード**: ESP32-S3-DevKitC-1
**確定日**: 2025-10-17
**基板**: WPCBB (Winch PCB Board)

---

## 📋 ピンアウト図

参照図:
- [esp32s3-devkitc-pinout-reference.png](../../notes/esp32s3-devkitc-pinout-reference.png) - 参照ピンアウト図
- [esp32s3-devkitc-actual-board.png](../../notes/esp32s3-devkitc-actual-board.png) - 実際のボード写真（シルク確認用）

---

## 🔌 確定ピンアサイン（実際のボード配置）

### 左側ヘッダー（上から下）

| シルク表記 | GPIO | 割り当て機能 | 詳細 |
|---|---|---|---|
| **3V3** | - | 3.3V電源 | - |
| **RST** | - | リセット | - |
| **4** | 4 | - | 未使用（予備） |
| **5** | 5 | - | 未使用（予備） |
| **6** | 6 | - | 未使用（予備） |
| **7** | 7 | - | 未使用（予備） |
| **15** | 15 | - | 未使用（予備） |
| **16** | 16 | - | 未使用（予備） |
| **17** | 17 | **TMC_TX** 🔵 | TMC2209診断（Serial2） |
| **18** | 18 | **TMC_RX** 🔵 | TMC2209診断（Serial2） |
| **8** | 8 | **TUBE_TX** 🟢 | 筒側通信（Serial1） |
| **3** | 3 | - | 未使用（Strapping Pin） |
| **46** | 46 | - | 未使用（Strapping Pin） |
| **9** | 9 | **TUBE_RX** 🟢 | 筒側通信（Serial1） |
| **10** | 10 | **TMC2209_EN** 🟡 | ステッパーイネーブル |
| **11** | 11 | **TMC2209_MS1** 🟡 | マイクロステップ設定 |
| **12** | 12 | **TMC2209_MS2** 🟡 | マイクロステップ設定 |
| **13** | 13 | **TMC2209_STEP** 🟡 | ステップパルス |
| **14** | 14 | **TMC2209_DIR** 🟡 | 方向制御 |
| **5V** | - | 5V電源 | - |
| **GND** | - | グランド | - |

### 右側ヘッダー（上から下）

| シルク表記 | GPIO | 割り当て機能 | 詳細 |
|---|---|---|---|
| **GND** | - | グランド | - |
| **TX** | 43 | - | 未使用（UART0 TX、デバッグ用） |
| **RX** | 44 | - | 未使用（UART0 RX、デバッグ用） |
| **1** | 1 | - | 未使用（予備） |
| **2** | 2 | **SOLENOID** 🔴 | 電磁ブレーキ制御 |
| **42** | 42 | - | 未使用（JTAG） |
| **41** | 41 | - | 未使用（JTAG） |
| **40** | 40 | - | 未使用（JTAG） |
| **39** | 39 | - | 未使用（JTAG） |
| **38** | 38 | **LED_C** 🟠 | Winch照明ON/OFF |
| **37** | 37 | - | 未使用（予備） |
| **36** | 36 | - | 未使用（予備） |
| **35** | 35 | **LED_PWM** 🟠 | Winch照明輝度（PWM） |
| **0** | 0 | - | 未使用（Boot/Strapping） |
| **45** | 45 | - | 未使用（Strapping） |
| **48** | 48 | **NeoPixel** 🟣 | オンボードLED（システムステータス） |
| **47** | 47 | - | 未使用（予備） |
| **21** | 21 | - | 未使用（予備） |
| **20** | 20 | - | 未使用（USB D+） |
| **19** | 19 | - | 未使用（USB D-） |
| **NC** | - | 未接続 | - |
| **GND** | - | グランド | - |

---

## 📊 機能別ピンアサイン一覧

### 🟣 システムステータス（オンボード）

| GPIO | 機能 | ボード位置 |
|---|---|---|
| **48** | NeoPixel RGB LED | 右側ヘッダー中央部 |

**詳細**: システムステータス表示用オンボードLED

---

### 🟢 UART1通信（筒側制御）

| GPIO | 信号 | ボード位置 |
|---|---|---|
| **8** | TUBE_TX | 左側ヘッダー中央上部 |
| **9** | TUBE_RX | 左側ヘッダー中央下部 |

**仕様**:
- ボーレート: 38400 baud
- 伝送路: TO WPCBMS経由、24V + GND + TX + RX
- 接続先: U3マイコン（筒内部）
- コネクタ位置: 基板左側（Wireless module）

---

### 🟡 TMC2209ステッパー制御

| GPIO | 信号 | ボード位置 |
|---|---|---|
| **10** | EN | 左側ヘッダー下部 |
| **11** | MS1 | 左側ヘッダー下部 |
| **12** | MS2 | 左側ヘッダー下部 |
| **13** | STEP | 左側ヘッダー下部 |
| **14** | DIR | 左側ヘッダー下部 |

**配置理由**: GPIO 10-14で連続5本、STEPPER_H2コネクタに近接

**マイクロステップ設定**:
| MS1 | MS2 | 分解能 |
|-----|-----|---|
| LOW | LOW | 1/8 |
| HIGH | LOW | 1/16 |
| LOW | HIGH | 1/32 |
| HIGH | HIGH | 1/64 |

---

### 🔵 UART2通信（TMC2209診断）

| GPIO | 信号 | ボード位置 |
|---|---|---|
| **17** | TMC_TX | 左側ヘッダー中央上部 |
| **18** | TMC_RX | 左側ヘッダー中央上部 |

**仕様**:
- ボーレート: 115200 baud
- 用途: TMC2209レジスタ読み書き、温度監視、ストール検出

---

### 🟠 LED Driver制御（Winch照明）

| GPIO | 信号 | ボード位置 |
|---|---|---|
| **35** | LED_PWM | 右側ヘッダー中央 |
| **38** | LED_C | 右側ヘッダー中央上部 |

**仕様**:
- ドライバIC: TPS92200DDCR (U2)
- LED: 既製品3W LED
- 電源: 24V
- PWM周波数: 5kHz
- PWM分解能: 8bit (0-255)

**配置理由**: TPS92200DDCR（右側中央）に近接

---

### 🔴 電磁ブレーキ制御

| GPIO | 信号 | ボード位置 |
|---|---|---|
| **2** | SOLENOID | 右側ヘッダー上部 |

**動作**:
| SOLENOID | Q2 | Q1 | ブレーキ |
|---|-----|-----|---|
| Hi-Z（起動時） | OFF | ON | **ON（安全）** |
| LOW | OFF | ON | **ON** |
| HIGH | ON | OFF | **OFF（解除）** |

**回路仕様**:
- Q2: NPN（R8=10kΩ、R6=100kΩプルダウン）
- Q1: 20N06 MOSFET
- フェイルセーフ: 起動時Hi-Z → プルダウン → ブレーキON

**配置理由**: ブレーキ回路Q2（左側下部）に近接

---

## 🎯 配線距離最適化の評価

### ✅ TMC2209グループ（GPIO 10-14, 17-18）

**左側ヘッダー配置**:
```
...
17 ──┐
18 ──┤ UART2（TMC2209診断）
8  ──┤
3    │
46   │
9  ──┤
10 ──┤
11 ──┤ TMC2209制御グループ（連続5本）
12 ──┤
13 ──┤
14 ──┘
...
```

- ✅ **連続配置**: GPIO 10-14で5本連続
- ✅ **物理的近接**: STEPPER_H2コネクタ（基板上部）に近い
- ✅ **配線距離**: 最短

---

### ✅ UART1グループ（GPIO 8-9）

**左側ヘッダー配置**:
```
...
17
18
8  ──┐ UART1（筒側通信）
3    │
46   │
9  ──┘
10
...
```

- ✅ **近接配置**: GPIO 8と9は2ピン離れているが、両方左側ヘッダー
- ✅ **物理的近接**: 電源通信コネクタ（基板左側）に近い
- ✅ **配線距離**: 短距離

---

### ✅ LED Driverグループ（GPIO 35, 38）

**右側ヘッダー配置**:
```
...
39
38 ──┐ LED Driver（Winch照明）
37   │
36   │
35 ──┘
0
...
```

- ✅ **近接配置**: GPIO 35と38は3ピン離れているが、両方右側ヘッダー中央
- ✅ **物理的近接**: TPS92200DDCR（右側中央）に近い
- ✅ **配線距離**: 短距離

---

### ✅ ブレーキ（GPIO 2）

**右側ヘッダー配置**:
```
GND
TX
RX
1
2  ── SOLENOID（ブレーキ）
42
...
```

- ✅ **物理的近接**: ブレーキ回路Q2（基板左下）へは横断が必要だが、右側上部から配線可能
- ⚠️ **配線距離**: やや長距離（基板を横断）

---

## 📝 使用GPIO統計

### 使用状況
- **使用中**: 13本
- **予備**: 22本
- **制約あり**: 11本（Strapping, USB, JTAG, UART0, 内部使用）

### 使用中GPIO詳細
```
GPIO 2:  SOLENOID (ブレーキ)
GPIO 8:  TUBE_TX (筒側通信)
GPIO 9:  TUBE_RX (筒側通信)
GPIO 10: TMC2209_EN
GPIO 11: TMC2209_MS1
GPIO 12: TMC2209_MS2
GPIO 13: TMC2209_STEP
GPIO 14: TMC2209_DIR
GPIO 17: TMC_TX (TMC2209診断)
GPIO 18: TMC_RX (TMC2209診断)
GPIO 35: LED_PWM (Winch照明)
GPIO 38: LED_C (Winch照明)
GPIO 48: NeoPixel (ステータス)
```

### 予備GPIO（拡張用）
```
GPIO 1, 4-7, 15-16, 21, 36-37, 47
```

---

## 🔧 ファームウェアGPIO定義

```cpp
// UART1（筒側通信）
#define TUBE_TX 8
#define TUBE_RX 9

// UART2（TMC2209通信）
#define TMC_TX 17
#define TMC_RX 18

// TMC2209制御
#define TMC2209_EN 10
#define TMC2209_MS1 11
#define TMC2209_MS2 12
#define TMC2209_STEP 13
#define TMC2209_DIR 14

// LED Driver（Winch照明用）
#define LED_C 38
#define LED_PWM 35

// 電磁ブレーキ
#define SOLENOID 2

// NeoPixel（システムステータス）
#define ONBOARD_LED_PIN 48
```

---

## 🔗 関連ドキュメント

| ドキュメント | 用途 |
|---|---|
| [wpcbb-pinout-analysis.md](wpcbb-pinout-analysis.md) | PCBレイアウト解析とGPIO最適配置 |
| [winch-u1-esp32s3-pinout.md](winch-u1-esp32s3-pinout.md) | 詳細ピンアサイン仕様（V2アーキテクチャ） |
| [esp32s3-devkitc-pinout-reference.png](../../notes/esp32s3-devkitc-pinout-reference.png) | 参照ピンアウト図 |
| [esp32s3-devkitc-actual-board.png](../../notes/esp32s3-devkitc-actual-board.png) | 実際のボード写真（シルク確認） |

---

## ✅ 次のアクション

1. **PCB回路図確認**
   - EasyEDA/KiCadで実際の配線を確認
   - このピンアサインと一致するか検証

2. **ファームウェア更新**
   - `main.cpp`, `globals.h`のGPIO定義を更新
   - 上記のGPIO定義を使用

3. **基板発注**
   - 締切: 2025-10-24

---

**優先度**: 🔴 最優先（2025-10-24発注締切）

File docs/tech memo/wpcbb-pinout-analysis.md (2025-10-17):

# WPCBB基板 ピンアサイン解析

**日付**: 2025-10-17
**基板**: WPCBB (Winch PCB Board)
**目的**: ESP32-S3最適ピンアサイン決定

---

## 📋 基板レイアウト分析

### H2ヘッダー（ESP32-S3-DevKitC-1）

**左側（上から下）**:
```
ピン番号 | GPIO | 備考
---------|------|------
GND      | -    |
21       | 21   |
20       | 20   | USB D+（使用注意）
19       | 19   | USB D-（使用注意）
18       | 18   |
17       | 17   |
16       | 16   |
15       | 15   |
14       | 14   |
13       | 13   |
12       | 12   |
11       | 11   |
10       | 10   |
9        | 9    |
8        | 8    |
7        | 7    |
6        | 6    |
5        | 5    |
4        | 4    |
3        | 3    | Strapping Pin
2        | 2    |
1        | 1    |
```

**右側（上から下）**:
```
ピン番号 | GPIO | 備考
---------|------|------
GND      | -    |
48       | 48   | NeoPixel（内蔵）
47       | 47   |
46       | 46   | Strapping Pin
45       | 45   | Strapping Pin
0        | 0    | Strapping Pin + Boot
35       | 35   |
36       | 36   |
37       | 37   |
38       | 38   |
39       | 39   | JTAG
40       | 40   | JTAG
41       | 41   | JTAG
42       | 42   | JTAG
43       | 43   | UART0 TX（デバッグ）
44       | 44   | UART0 RX（デバッグ）
```

---

## 🎯 コンポーネント配置の確認

### 1. STEPPER_H2コネクタ（上部中央）

**位置**: 基板上部、ピン8-1の近く
**接続先**: TMC2209信号線

**物理的に近いGPIOピン**:
- GPIO 8-15（左側上部）

### 2. STEPPERモーターコネクタ（左上）

**信号**: BLK A+, GRN A-, RED B+, BLU B-
**トレース**: 40mil（修正済み）

### 3. LED Driver周辺（右側中央）

**IC**: TPS92200DDCR (U2)
**制御信号**: LED_C, LED_PWM
**出力**: LED_A

**物理的に近いGPIOピン**:
- GPIO 35-38（右側中央）

### 4. 電磁ブレーキ回路（下部）

**IC**: Q1 (20N06), Q2 (NPN)
**制御信号**: SOLENOID
**出力**: S_DRN

**物理的に近いGPIOピン**:
- GPIO 1-4（左側下部）

### 5. 電源通信コネクタ（"Wireless module"ラベル）

**信号**: 24V, S_DRN, TX, RX（筒側通信用）
**位置**: 基板左側

**物理的に近いGPIOピン**:
- GPIO 8-10（左側上部）

---

## 📊 ESP32-S3制約の確認

### 使用禁止GPIO
- **GPIO 26-32**: SPI Flash/PSRAM内部使用
- **GPIO 33-37**: SPI Flash（オクタル）内部使用

### 注意が必要なGPIO
- **GPIO 0**: Boot button（プルアップ必須）
- **GPIO 3, 45, 46**: Strapping Pins（プルアップ/ダウン注意）
- **GPIO 19, 20**: USB D-/D+（USB使用時は不可）
- **GPIO 39-42**: JTAG（デバッグ使用時は不可）
- **GPIO 43, 44**: UART0（デバッグ用、変更非推奨）

### PWM対応GPIO
ESP32-S3は全GPIOでPWM使用可能（LEDC）

---

## 🔧 最適ピンアサイン決定

### 原則
1. **配線距離最小化**: コンポーネントに物理的に近いGPIOを使用
2. **制約回避**: Strapping Pins, USB, JTAG, UART0を避ける
3. **グルーピング**: 関連信号は連続したGPIOに配置

### ピンアサイン案

#### UART1（筒側通信）
**要件**: Serial1, 電源通信コネクタに近い
**候補**: GPIO 8-10の範囲

| 信号 | GPIO | 理由 |
|---|---|---|
| UART1_TX | **8** | 左側上部、コネクタに近い |
| UART1_RX | **9** | GPIO 8の隣、連続配置 |

#### TMC2209制御
**要件**: STEPPER_H2コネクタに近い、GPIO連続配置

| 信号 | GPIO | 理由 |
|---|---|---|
| TMC2209_EN | **10** | STEPPER_H2に近い |
| TMC2209_MS1 | **11** | GPIO 10の隣 |
| TMC2209_MS2 | **12** | GPIO 11の隣 |
| TMC2209_STEP | **13** | GPIO 12の隣 |
| TMC2209_DIR | **14** | GPIO 13の隣 |

#### UART2（TMC2209診断）
**要件**: Serial2, TMC2209制御信号に近い

| 信号 | GPIO | 理由 |
|---|---|---|
| UART2_TX | **17** | TMC2209グループに近い |
| UART2_RX | **18** | GPIO 17の隣 |

#### LED Driver（Winch照明）
**要件**: PWM対応、TPS92200DDCRに近い

| 信号 | GPIO | 理由 |
|---|---|---|
| LED_C | **38** | 右側中央、U2に近い |
| LED_PWM | **35** | GPIO 38の近く、PWM対応 |

#### 電磁ブレーキ
**要件**: ブレーキ回路に近い

| 信号 | GPIO | 理由 |
|---|---|---|
| SOLENOID | **2** | 左側下部、Q2に近い |

#### システムステータス
**確定済み**:

| 信号 | GPIO | 理由 |
|---|---|---|
| NeoPixel | **48** | オンボードLED（内蔵） |

---

## 📝 最終ピンアサイン表

| GPIO | 機能 | 接続先 | シリアル | 備考 |
|---|---|---|---|---|
| **48** | NeoPixel | オンボード | - | システムステータス表示 |
| **8** | UART1_TX | 筒側コネクタ | Serial1 | 電源通信ケーブル |
| **9** | UART1_RX | 筒側コネクタ | Serial1 | 電源通信ケーブル |
| **10** | TMC2209_EN | TMC2209 | - | イネーブル（LOW=有効） |
| **11** | TMC2209_MS1 | TMC2209 | - | マイクロステップ設定 |
| **12** | TMC2209_MS2 | TMC2209 | - | マイクロステップ設定 |
| **13** | TMC2209_STEP | TMC2209 | - | ステップパルス |
| **14** | TMC2209_DIR | TMC2209 | - | 方向制御 |
| **17** | UART2_TX | TMC2209 | Serial2 | 診断・設定用 |
| **18** | UART2_RX | TMC2209 | Serial2 | 診断・設定用 |
| **2** | SOLENOID | ブレーキ回路 | - | フェイルセーフ設計 |
| **35** | LED_PWM | TPS92200DDCR | PWM | Winch照明輝度 |
| **38** | LED_C | TPS92200DDCR | - | Winch照明ON/OFF |

### 使用GPIO数
**合計**: 13本 / 35本使用可能

### 未使用GPIO（拡張用）
- GPIO 1, 3-7, 15-16, 21, 36-37, 39-47

---

## ✅ 配線シンプル性の評価

### TMC2209グループ（GPIO 10-14, 17-18）
- ✅ **連続配置**: GPIO 10-14で5本連続
- ✅ **物理的近接**: 基板上部のSTEPPER_H2コネクタに近い
- ✅ **配線距離**: 最短ルートで配線可能
- ✅ **UART2**: GPIO 17-18で近傍に配置

### UART1グループ（GPIO 8-9）
- ✅ **連続配置**: GPIO 8-9で2本連続
- ✅ **物理的近接**: 電源通信コネクタ（Wireless module）に近い
- ✅ **配線距離**: 左側上部で最短

### LED Driverグループ（GPIO 35, 38）
- ✅ **物理的近接**: 右側中央のU2（TPS92200DDCR）に近い
- ⚠️ **非連続**: GPIO 35と38で間隔あり（やむを得ず）
- ✅ **配線距離**: 右側配置で最短

### ブレーキ（GPIO 2）
- ✅ **物理的近接**: 左側下部のQ2（ブレーキ回路）に近い
- ✅ **単独配置**: 1本のみなので問題なし

---

## 🎨 配線経路のビジュアル

```mermaid
graph LR
    subgraph ESP32["ESP32-S3 H2ヘッダー"]
        G8[GPIO 8-9<br/>UART1]
        G10[GPIO 10-14<br/>TMC2209]
        G17[GPIO 17-18<br/>UART2]
        G2[GPIO 2<br/>SOLENOID]
        G35[GPIO 35,38<br/>LED]
        G48[GPIO 48<br/>NeoPixel]
    end

    subgraph Components["コンポーネント"]
        Tube[筒側コネクタ<br/>左側]
        TMC[STEPPER_H2<br/>上部中央]
        LED[TPS92200DDCR<br/>右側中央]
        Brake[ブレーキ回路<br/>下部]
    end

    G8 -.短距離.-> Tube
    G10 -.短距離.-> TMC
    G17 -.短距離.-> TMC
    G35 -.中距離.-> LED
    G2 -.短距離.-> Brake

    style G8 fill:#e1f5fe
    style G10 fill:#c8e6c9
    style G17 fill:#c8e6c9
    style G2 fill:#fff9c4
    style G35 fill:#ffe0b2
    style G48 fill:#f3e5f5
```

---

## 🔗 次のアクション

### ~~1. winch-u1-esp32s3-pinout.md を更新~~ ✅ 完了（2025-10-17）
   - ✅ TBD → 確定GPIO番号に置き換え完了
   - ✅ コード例を全て更新
   - ✅ ファームウェアチェックリスト更新

### 2. ファームウェア修正（ローカルVS Codeで実施）
   - [ ] main.cpp, globals.h のGPIO定義を更新
   - [ ] I2C関連コード削除（U2廃止）
   - [ ] デュアルコアタスク実装

### 3. PCB回路図確認 ⏩ 次のステップ
   - [ ] EasyEDA/KiCadで回路図を開く
   - [ ] 実際の配線がこのピンアサインと一致するか確認
   - [ ] 不一致があれば回路図修正 or ピンアサイン変更

### 4. テスト計画（基板到着後）
   - [ ] 各GPIO動作確認
   - [ ] 通信テスト（UART1, UART2）
   - [ ] TMC2209制御テスト

---

**優先度**: 🔴 最優先（2025-10-24発注締切）

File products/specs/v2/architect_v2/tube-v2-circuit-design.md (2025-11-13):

# Tube V2 回路設計仕様書

**プロジェクト**: Fragmentations of Unity - Nagoya Installation
**対象**: 吊り下げ筒本体 V2（HD統合制御方式）
**作成日**: 2025-11-09
**ステータス**: 🔄 設計中

---

## 概要

V2では、HD（Horozon Disc）に2基のESP32-S3を搭載し、GR/CRリングと通信しながら全体を制御する。
スリップリングを介してWinchと接続し、YAWモーターで自由回転、Pitchサーボで姿勢制御を実現。

---

## V1からの主要変更点

| 項目 | V1 | V2 |
|---|----|----|
| **マイコン** | RP2040-Zero × 2 | ESP32-S3 × 2 (4コア) |
| **LED総数** | 48個 (24+24) | 96個 (48+48) |
| **センサー統合** | 各基板独立 | HD集中管理 |
| **通信方式** | U3→U4 UART連鎖 | HD→PR I2C×2系統 + NeoPixel |
| **Pitch制御** | BLDC | BLDCモーター + 可変抵抗 50kΩ |
| **YAW制御** | BLDC（背面） | BLDC（HD下部） |
| **新規機能** | - | スリップリング角度検出 |

---

## システム構成

### コンポーネント仕様書

各コンポーネントの詳細仕様は以下を参照:

| コンポーネント | 仕様書 |
|---|---|
| **マイコン** | [ESP32-S3](../Component/ESP32-S3.md) |
| **エンコーダー** | [AS5600](../Component/AS5600.md) |
| **センサー** | [GridEye AMG8833](../Component/GridEye-AMG8833.md) / [GY-85](../Component/GY-85.md) |
| **LED** | [NeoPixel WS2812B](../Component/NeoPixel-WS2812B.md) / [NeoPixel信号仕様](../Component/NeoPixel-Signal.md) |
| **電源** | [DCDC変換器](../Component/DCDC-Converter.md) |
| **モーター** | [BLDC Pitchモーター](../Component/BLDC-Pitch-Motor.md) / [BLDC YAWモーター](../Component/BLDC-YAW-Motor.md) / [リアクションホイール WSSB50-30-10](../Component/Reaction-Wheel-WSSB50-30-10.md) |
| **角度センサー** | [可変抵抗 RK0971210](../Component/Variable-Resistor-RK0971210.md) |
| **機構** | [スリップリング](../Component/SlipRing.md) / [プーリー](../Component/Pulley.md) / [PR取付機構](../Component/PR-Mount.md) / [真鍮線](../Component/BrassWire.md) |
| **ケーブル** | [4極ケーブル](../Component/Cable-4pole.md) |
| **基板** | [HD Board](../Component/HD-Board.md) / [GR/CR Board](../Component/GR-CR-Board.md) |
| **通信** | [I2Cインターフェース](../Component/I2C-Interface.md) / [UARTプロトコル](../Component/UART-Protocol.md) |

### システム構成図

```mermaid
graph TB
    subgraph Winch["🔌 Winch（天井固定）"]
        ESP32S3_U1[ESP32-S3 U1<br/>WiFi/MQTT]
        Pulley[プーリー]
        Winch_Female[4極ミニプラグ メス<br/>着脱可能]
    end

    Cable4_MaleToMale[4極ステレオミニプラグケーブル<br/>両端オス<br/>24V/GND/TX/RX]

    subgraph SlipRing["🔄 スリップリング"]
        SR[連続回転機構<br/>角度検知用磁石内蔵]
        Cable4_Female[4極ミニプラグ メス]
    end

    AS_S[AS5600 エンコーダー<br/>スリップリング横配置<br/>ケーブル相対回転角度]

    subgraph HD["💿 Horozon Disc（HD）"]
        ESP32S3_1[ESP32-S3 #1<br/>Core0: WiFi/UART<br/>Core1: センサー統合]
        ESP32S3_2[ESP32-S3 #2<br/>Core0: YAWモーター<br/>Core1: Pitchモーター]
        DCDC_5V[DCDC 5V 10A<br/>NeoPixel用]
        DCDC_3V3[DCDC 3.3V 1A<br/>ESP32-S3/センサー用]
        BLDC_Pitch[BLDCモーター<br/>Pitch軸回転]
        VR_Pitch[可変抵抗 50kΩ<br/>GPIO10 ADC<br/>Pitch角度検出]
        AS_Y[AS5600 エンコーダー<br/>YAWモーター角度検出]

        ESP32S3_1 -.Core間通信.- ESP32S3_2
    end

    subgraph YAW["🌀 YAWモーター（HD下部）"]
        BLDC_YAW[BLDC モーター]
        ReactionWheel[リアクションホイール<br/>WSSB50-30-10<br/>慣性モーメント増加]
    end

    subgraph PR["⭕ Pitch Ring（PR）"]
        PR_Mount[PR取付機構<br/>5V/GND/I2C0/I2C1/NeoPixel配線]
    end

    subgraph GR["🎨 Grideye Ring（GR・前面）"]
        GR_LED[NeoPixel 前24 + 後24]
        GridEye[GridEye センサー]
    end

    subgraph CR["🧭 Compass Ring（CR・背面）"]
        CR_LED[NeoPixel 前24 + 後24]
        GY85[GY-85 9軸センサー]
    end

    %% コンポーネントリンク
    click ESP32S3_U1 "../Component/ESP32-S3.md" "ESP32-S3仕様"
    click ESP32S3_1 "../Component/ESP32-S3.md" "ESP32-S3仕様"
    click ESP32S3_2 "../Component/ESP32-S3.md" "ESP32-S3仕様"
    click Pulley "../Component/Pulley.md" "プーリー仕様"
    click Cable4_MaleToMale "../Component/Cable-4pole.md" "4極ケーブル仕様"
    click AS_S "../Component/AS5600.md" "AS5600仕様"
    click AS_Y "../Component/AS5600.md" "AS5600仕様"
    click SR "../Component/SlipRing.md" "スリップリング仕様"
    click DCDC_5V "../Component/DCDC-Converter.md" "DCDC 5V仕様"
    click DCDC_3V3 "../Component/DCDC-Converter.md" "DCDC 3.3V仕様"
    click BLDC_Pitch "../Component/BLDC-Pitch-Motor.md" "BLDC Pitchモーター仕様"
    click VR_Pitch "../Component/Variable-Resistor-RK0971210.md" "可変抵抗仕様"
    click PR_Mount "../Component/PR-Mount.md" "PR取付機構仕様"
    click GR_LED "../Component/NeoPixel-WS2812B.md" "NeoPixel仕様"
    click CR_LED "../Component/NeoPixel-WS2812B.md" "NeoPixel仕様"
    click GridEye "../Component/GridEye-AMG8833.md" "GridEye仕様"
    click GY85 "../Component/GY-85.md" "GY-85仕様"
    click BLDC_YAW "../Component/BLDC-YAW-Motor.md" "BLDCモーター仕様"
    click ReactionWheel "../Component/Reaction-Wheel-WSSB50-30-10.md" "リアクションホイール仕様"
    click HD "../Component/HD-Board.md" "HD Board仕様"
    click GR "../Component/GR-CR-Board.md" "GR Board仕様"
    click CR "../Component/GR-CR-Board.md" "CR Board仕様"

    ESP32S3_U1 --> Pulley
    Pulley --> Winch_Female
    Winch_Female -->|ジャック接続| Cable4_MaleToMale
    Cable4_MaleToMale -->|ジャック接続| Cable4_Female
    Cable4_Female --> SR
    SR --> Cable4_Female
    Cable4_Female -->|24V/GND/TX/RX| DCDC_5V
    Cable4_Female -->|24V/GND| DCDC_3V3
    DCDC_3V3 -->|3.3V| ESP32S3_1
    DCDC_3V3 -->|3.3V| ESP32S3_2
    DCDC_5V -->|5V| PR_Mount

    SR -.磁石.- AS_S
    AS_S -->|I2C| ESP32S3_2

    DCDC_5V -->|5V| PR_Mount
    ESP32S3_1 -->|GND/I2C0/I2C1| PR_Mount
    ESP32S3_1 -->|Neo output1| PR_Mount
    ESP32S3_2 -->|I2C| AS_Y
    ESP32S3_2 -->|FOC制御| BLDC_YAW
    ESP32S3_2 -->|GPIO10 ADC| VR_Pitch
    ESP32S3_2 -->|GPIO14/15/16 PWM| BLDC_Pitch

    BLDC_Pitch -.Pitch軸回転.- PR_Mount
    VR_Pitch -.角度検出.- BLDC_Pitch

    PR_Mount -->|I2C0| GridEye
    PR_Mount -->|I2C1| GY85
    PR_Mount -->|Neo output1| GR_LED
    GR_LED -->|Neo output2| PR_Mount
    PR_Mount -->|Neo output2中継| CR_LED

    PR_Mount -.6本真鍮線.- GR
    PR_Mount -.6本真鍮線.- CR
    HD -.取付.- PR_Mount
    HD -.軸.- BLDC_YAW
    BLDC_YAW -.軸固定.- ReactionWheel
```

---

## 設計方針

### 設計目標
- ESP32-S3 デュアルコア×2基で4コアフル活用
- HD集中制御によるセンサー統合
- スリップリング対応でケーブルねじれ検出
- Pitch BLDC化による精密制御（可変抵抗フィードバック）
- YAWモーター自由回転による方向制御

### 設計制約
- 電源: 24V入力（Winchから供給）
- 通信: スリップリング経由UART（TX/RX、38400 baud）
- LED: NeoPixel WS2812B × 96個（GR 48個 + CR 48個）
- センサー: GridEye + GY-85 + AS5600×2

---

## ハードウェア構成

### 1. Horozon Disc (HD)

**マイコン: ESP32-S3 × 2**

#### オプション1: 2基ESP32-S3構成（提案）

| ESP32-S3 | Core | 担当処理 | 主要タスク |
|---|---|---|---|
| **#1** | Core 0 | WiFi/MQTT/UART | Winch通信、GR/CR通信 |
| **#1** | Core 1 | センサー統合 | GridEye + GY-85データ収集・処理 |
| **#2** | Core 0 | YAWモーター制御 | BLDC FOC制御、AS-Y読取 |
| **#2** | Core 1 | Pitchモーター制御 | BLDC FOC制御、可変抵抗ADC読取、AS-S読取 |

**メリット:**
- 各タスクを完全分離、リアルタイム性向上
- 負荷分散でCPU余裕確保
- 片方クラッシュしても他方継続可能

**デメリット:**
- 基板面積増加、コスト増
- ESP32-S3間通信オーバーヘッド

#### オプション2: 1基ESP32-S3構成（簡素化案）

| Core | 担当処理 | 主要タスク |
|---|---|---|
| Core 0 | WiFi/MQTT/UART + センサー統合 | Winch通信、GR/CR通信、GridEye/GY-85処理 |
| Core 1 | モーター制御 | YAWモーター FOC、Pitch BLDC FOC、可変抵抗ADC、AS5600×2読取 |

**メリット:**
- 基板簡素化、コスト削減
- 配線削減

**デメリット:**
- CPU負荷高、リアルタイム性低下の可能性
- センサー処理とWiFi処理が競合

**決定**: （未定 - 負荷試算待ち）

---

**電源回路:**
- 入力: 24V DC（スリップリング経由）
- 出力: 5V 2A DCDC
- レギュレータ候補:
  - LM2596 (3A, 〜92%)
  - MP1584 (3A, 〜96%)
  - XL4015 (5A, 〜94%)

**決定**: （未定）

**消費電力試算:**
- ESP32-S3 × 2: 500mA（WiFi送信時）
- Pitch BLDCモーター: 500mA（動作時、電圧制限1.5V）
- YAW BLDCモーター: 1A（最大）
- NeoPixel LED: 1.5A（96個、全点灯時）
- **合計**: 約3.5A（安全マージン考慮で5V 10A DCDC使用）

---

**センサー接続:**

| センサー | インターフェース | 用途 |
|---|---|---|
| AS5600 (AS-S) | I2C | スリップリング角度検出 |
| AS5600 (AS-Y) | I2C | YAWモーターエンコーダー |
| 可変抵抗 50kΩ | ADC (GPIO10) | Pitchモーター角度検出（0-300°、12bit分解能） |

---

**通信プロトコル:**

**HD → PR配線 (5線):**
```
1. 5V電源
2. GND
3. I2C0 (SDA/SCL) - GridEye接続用
4. I2C1 (SDA/SCL) - GY-85接続用
5. NeoPixel Data - GR/CR LED制御用（シリアル信号）
```

**センサー接続:**
```
GridEye (GR) → I2C0 → HD (ESP32-S3 #1)
GY-85 (CR)   → I2C1 → HD (ESP32-S3 #1)
```

**LED制御:**
```
HD → NeoPixel Data → GR LED (48個) → CR LED (48個)
```

**HD ↔ Winch (UART 38400 baud、既存プロトコル維持):**
```
Winch → HD: "DATA,F,r,g,b,R,r,g,b,P,pitch,yaw,B,brightness,H,enc_horizontal\n"
HD → Winch: センサーデータフィードバック（形式未定）
```

---

### 2. Pitch Ring (PR) と Pitchモーター

**構成:**
- BLDCモーター: HD基板上に実装（V1 Tube U3と同型）
- 可変抵抗 50kΩ: Pitch角度フィードバック用
- PR取付機構: モーター軸経由でGR/CRを固定

**BLDCモーター: Pitch制御用（HD搭載）**

| 項目 | 仕様 |
|---|---|
| 制御信号 | 3相PWM (GPIO14/15/16) |
| 極対数 | 7 |
| 相抵抗 | 6.5Ω |
| KV値 | 330 |
| 制御ライブラリ | SimpleFOC v2.3.4 |
| 制御モード | 速度制御 + 位置フィードバック |
| 電圧制限 | 1.5V |
| 速度制限 | 1.3 rad/s |
| **配置** | **HD基板上** |

**可変抵抗: RK0971210-F15-C0-B503**

| 項目 | 仕様 |
|---|---|
| 抵抗値 | 50kΩ (±20%) |
| 回転角度 | 300° (電気角) |
| 出力電圧 | 0-3.3V |
| GPIO | GPIO10 (ESP32-S3 ADC) |
| 分解能 | 12-bit (0-4095) |
| 用途 | Pitch角度フィードバック |

**制御方式:**
- SimpleFOC速度制御モード
- 可変抵抗ADC読取で現在角度取得（0-300°）
- 位置フィードバック: 目標角度と現在角度の差分から目標速度を計算
- PIDパラメータ: P=0.1, I=0.3, D=0.01（V1最適値を継承）
- 位置制御ゲイン: 2.5
- 最大速度制限: 1.2 rad/s
- デッドバンド: ±0.015 rad（約0.86°）

**キャリブレーション:**
- ユーザーが手動で0°と300°位置に設定
- ADC最小値・最大値を記録
- 実測ADC範囲を300°にマッピング

**機構:**
- モーター本体: HD基板に固定
- モーター軸: PR取付機構を介してGR/CR Ringを固定
- Pitch軸回転: モーター回転でGR/CRが傾く
- 可変抵抗: モーター軸に連動して回転

**決定事項:**
- [x] モーター制御方式: SimpleFOC速度制御 + 位置フィードバック
- [x] 角度センサー: 可変抵抗 50kΩ (RK0971210)
- [x] GPIO割当: PWM (GPIO14/15/16), ADC (GPIO10)
- [ ] モーター軸と可変抵抗の機械的連結方法
- [ ] HD基板上のモーター実装位置

---

### 3. Grideye Ring (GR) / Compass Ring (CR)

**仕様:**
- NeoPixel: 前面24個 + 背面24個 = 48個/基板
- センサー: GR = GridEye、CR = GY-85
- **制御マイコン: なし（センサーとLEDのみ）**

**接続方式:**
- **GridEye (GR)**: I2C0系統で直接HD (ESP32-S3 #1) に接続
- **GY-85 (CR)**: I2C1系統で直接HD (ESP32-S3 #1) に接続
- **NeoPixel (GR/CR)**: シリアルデータ線で直接HD制御
- **電源**: 5V/GND はPR経由でHDから供給

**配線構成:**
```
HD → PR取付機構 → GR/CR
  ↓
5V/GND/I2C0/I2C1/NeoPixel Data (5線)
```

**決定事項:**
- [ ] PRからGR/CRへの配線方法（コネクタ or 直付け）
- [ ] I2C0/I2C1のプルアップ抵抗配置（HD側 or PR側）
- [ ] NeoPixel データ線のシグナルインテグリティ対策

---

### 4. スリップリング

**仕様:**
- 4極ミニプラグ対応（24V / GND / TX / RX）
- 連続回転可能
- **角度検知用磁石内蔵**: スリップリング回転機構内に磁石を配置

**AS5600 (AS-S) 配置:**
- **位置**: スリップリングの横（外側）に配置
- **磁石**: スリップリング回転機構内に内蔵
- インターフェース: I2C
- 分解能: 12-bit (0-4095)
- 用途: ケーブル相対回転角度検出（0-360°）
- **測定対象**: Winchから吊り下がるケーブルの回転角度（スリップリング磁石の回転を検知）

**制御ロジック:**
```cpp
// ケーブルねじれ検出
if (abs(cable_rotation_angle) > 180°) {
  // YAWモーター逆回転でケーブル巻き戻し
  apply_yaw_correction();
}
```

**決定事項:**
- [ ] スリップリング製品選定（型番）
- [x] AS5600配置: スリップリング横（外側）
- [x] 磁石配置: スリップリング回転機構内に内蔵
- [ ] AS5600取付構造設計（スリップリング横の固定方法）
- [ ] ケーブル巻き戻し閾値（何度でアラート？）

---

### 5. YAWモーター

**仕様:**
- 型番: （V1と同じBLDC想定）
- 制御: SimpleFOC + AS5600エンコーダー (AS-Y)
- 最大速度: 80 rad/s（V1 U4と同等）

**制御モード:**
1. **角度制御モード**: 目標YAW角度に追従
2. **ケーブル補正モード**: AS-S角度に基づき自動補正
3. **Sparkモード**: 最高速回転演出

**決定事項:**
- [ ] YAWモーター取付構造（HD下部固定方法）
- [ ] AS5600 (AS-Y) 磁石配置
- [ ] ケーブル補正PIDパラメータ

---

## 未決定事項

### 高優先度
- [ ] ESP32-S3の台数（1基 or 2基）
- [ ] GR/CR基板マイコン選定（RP2040継続 or ESP32-C3）
- [ ] HD↔GR/CR通信方式（UART or I2C or SPI）
- [ ] DCDC選定（LM2596 / MP1584 / XL4015）
- [ ] 電源供給方法（GR/CRへの配線）

### 中優先度
- [ ] スリップリング製品選定
- [ ] AS5600 (AS-S) 磁石取付方法
- [ ] Pitchサーボ電源供給方法
- [ ] YAWモーター取付構造
- [ ] ケーブル巻き戻し閾値設定

### 低優先度
- [ ] HD基板サイズ・形状
- [ ] 筒内実装レイアウト
- [ ] ファームウェアアーキテクチャ詳細
- [ ] 量産時の組み立て手順

---

## 次のアクション

1. **ESP32-S3台数決定**: 負荷試算・コスト比較
2. **GR/CR基板仕様確定**: マイコン・通信方式選定
3. **電源設計**: DCDC選定・消費電流詳細試算
4. **スリップリング選定**: 製品リサーチ・AS5600統合方法

---

## 関連ドキュメント

- [PROGRESS.md](../../PROGRESS.md) - プロジェクト全体進捗
- [V1 U3ファームウェア](../../products/firmware/v1/Tube_v1/FU_TUBE_RP2040_U3/)
- [V1 U4ファームウェア](../../products/firmware/v1/Tube_v1/FU_TUBE_RP2040_U4/)

---

## 変更履歴

| 日付 | 変更内容 | 担当 |
|---|---|---|
| 2025-11-09 | V2構成初版作成（HD統合制御方式） | kyopan |
| 2025-11-09 | AS5600 (AS-S) 配置修正（スリップリング上部・ケーブルメス側） | kyopan |
| 2025-11-09 | RCサーボ DS-M005 配置修正（HD基板上に実装） | kyopan |
| 2025-11-09 | Winch-スリップリング間に4極ステレオミニプラグケーブル（両端オス）追加 | kyopan |
| 2025-11-09 | AS5600 (AS-S) 配置再修正（スリップリング横、磁石はスリップリング内蔵） | kyopan/CIC |
| 2025-11-09 | PR固定方法を「6本真鍮線（はんだ固定）」に変更、真鍮線仕様書追加 | kyopan/CIC |
| 2025-11-09 | リアクションホイール WSSB50-30-10 追加（YAWモーター慣性増加用） | kyopan/CIC |
| 2025-11-09 | 電源系統修正: DCDC 5V 10A (NeoPixel用) + DCDC 3.3V 1A (ESP32-S3/センサー用) 2系統化 | kyopan/CIC |
| 2025-11-09 | NeoPixel配線修正: output1 (HD→PR→GR) / output2 (GR→PR→CR) デイジーチェーン構成 | kyopan/CIC |
| 2025-11-13 | Pitch制御をRCサーボからBLDCモーター+可変抵抗50kΩに変更 | kyopan/CIC |
| 2025-11-13 | GPIO割当追加: GPIO10 (可変抵抗ADC), GPIO14/15/16 (BLDC PWM) | kyopan/CIC |

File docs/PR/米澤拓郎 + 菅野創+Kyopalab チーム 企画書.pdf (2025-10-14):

# ⽶澤拓郎 + 菅野創 + Kyopalab チーム 企画書

# メンバー紹介

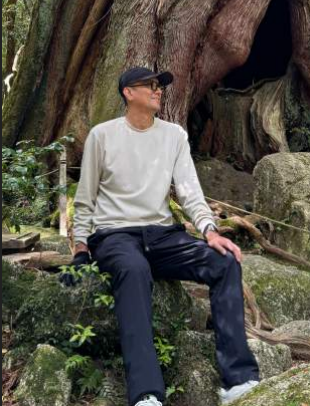
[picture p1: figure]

## ⽶澤 拓郎

名古屋⼤学⼯学研究科情報‧通信専攻准教授

現在の研究テーマは

「異なる現実をセキュアにつなぐ情報技術と、そ
れが実現する新たな価値‧社会像」

主なプロジェクト：

JST CREST「多様な形態の現実を安⼼‧安全に創 り‧繋ぐTrusted Inter-Reality基盤」(2022-2028)

JST RISTEX 「サービス‧モビリティと多形態コ ミュニティの繋がりによる社会的孤⽴‧孤独予防
モデル」(2023-2027)

## 菅野 創

愛知県⽴芸術⼤学美術学部メディア映像専攻
特任教授

IAMAS(情報科学芸術⼤学院⼤学)修了

2013年よりベルリンを拠点に活動

多数のロボットを使ったインスタレーションを
多く制作する。

⽂化庁メディア芸術祭優秀賞2回、新⼈賞１回

Prix Ars Electronica Honorary Mention受賞2回

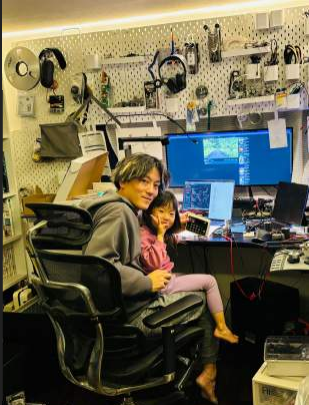
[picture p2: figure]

## 興野 悠太郎

慶應義塾⼤学政策‧メディア研究科博⼠課程在学
Kyopalab合同会社代表

在学中、抗がん剤などに利⽤される分⼦標的薬を
設計するバイオベンチャーを創業。
創薬の現場にて完全⾃動機械の重要性を痛感した
ためロボティクスを独学で学び、ゼロから何でも
作れるラボを⽬指したKyopalab合同会社を設⽴。

TEDxHanedaにて登壇 ほか受賞多数

JST CREST「多様な形態の現実を安⼼‧安全に創 り‧繋ぐTrusted Inter-Reality基盤」(2022-2028)

⽶澤先⽣のご紹介の下、本プロジェクトに参画

## タイトル「Fragmentations of Unity」(仮）

群と個をテーマにしたインスタレーション

「断⽚化」「分裂」「分散」といった意味をもつFragmentationと

「統⼀」「結束」といった意味を持つUnityと組み合わせることによって

反義語がつながり、ねじれたような⽭盾するようなバランスと 緊張感の発⽣を意図しています。

# コンセプト

## コンセプト

このプロジェクトは、群と個の間に存在するダイナミクスを探求し、鑑賞者に新 たな視点を提供する群ロボットインスタレーションです。

ロボットたちは互いに影響を与え合い、鑑賞者からの影響も受けながら、振る舞 います。共鳴する振る舞いは群⾏動へと広がりますが、必ずしも全体が共鳴する とは限りません。

⾃然界の多くのシステムがバランスを保ちながら変化するように、この作品で は、集団としての調和と個々の振る舞いが交錯する様⼦が描かれます。鑑賞者は 作品の体験を通じて、集団の中における個の役割や影響⼒を考察し、より広い視 点を得ることができるでしょう。

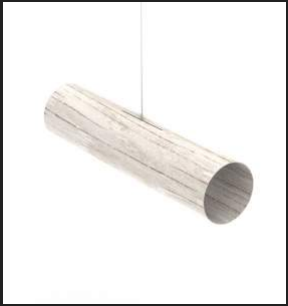
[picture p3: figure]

## ロボットの形状は筒型

向きを持つ最もミニマルな形状です。
この形状は、動きや⽅向性を表現するのに
必要最⼩限の形態であり、プリミティブな
存在を象徴しています。

⽣物進化の初期段階で「⾷べる」ための消
化管が形成され、そこから「⼊⼝」と「出
⼝」が⽣まれることで、⾃然と⽅向性が発
⽣しました。

## 筒ロボットの振る舞い

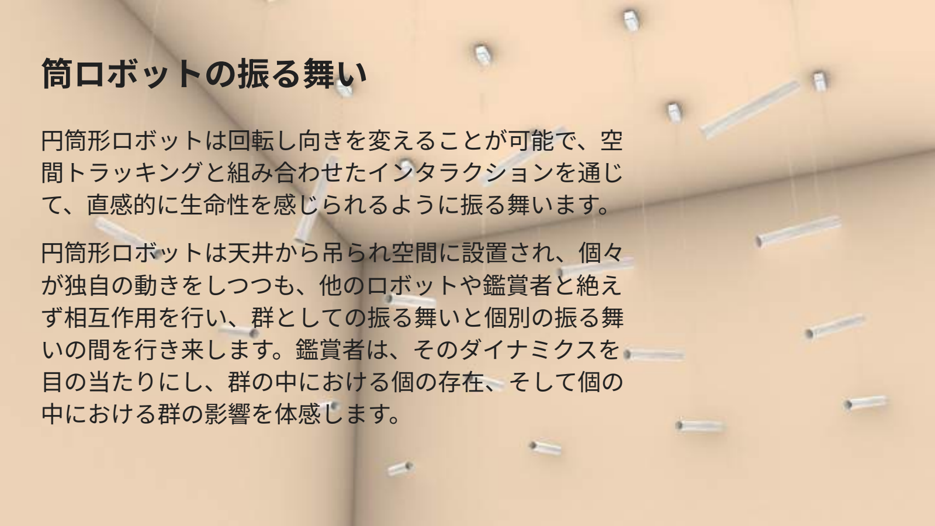
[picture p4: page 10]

円筒形ロボットは回転し向きを変えることが可能で、空
間トラッキングと組み合わせたインタラクションを通じ
て、直感的に⽣命性を感じられるように振る舞います。

円筒形ロボットは天井から吊られ空間に設置され、個々
が独⾃の動きをしつつも、他のロボットや鑑賞者と絶え
ず相互作⽤を⾏い、群としての振る舞いと個別の振る舞
いの間を⾏き来します。鑑賞者は、そのダイナミクスを
⽬の当たりにし、群の中における個の存在、そして個の
中における群の影響を体感します。

## インタラクションの設計⽅針

動物や⼈間が持つノンバーバルなコミュニケーションの様式を、 ミニマルなロボットたちが再現します。⾮⾔語的なコミュニケー ションによって感情や意思が相互に感じ取られる。

それを通じて鑑賞者が⾃らの⽴場や役割を投影する場を提供しま す。

鑑賞者に固定的な⾒解を押し付けるものではなく、むしろ多様な 解釈を可能なものにしたい。

## ところで、アイデアの起こり

私達は⾃⼰紹介とブレストを経て、作品のアイデアの⽅向性を

菅野がインスタレーションのスタイルとして確⽴してきている 多数のロボットを使うシステムと

⽶澤先⽣の研究の「共有リアリティ」というキーワードを関連付 けて考えていくことになりました

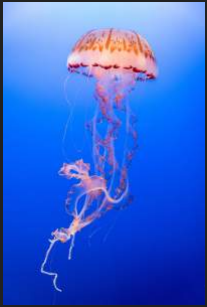
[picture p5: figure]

## クラゲ → 筒へ

クラゲとはコミュニケーションが取れる気がしな
い、共有できるリアリティがなさそう

では逆に最低限コミュニケーションを取れそうな気
がするには、どんな条件が要るのだろうか

消化管を持つ動物は向きがある、向きがある連中と
は向き合える気がする

管のプリミティブ形状は筒だ！
このようにして、筒状の形のロボットを作ろうとい
うアイデアが⽣まれました

# 設計概要‧主な仕様

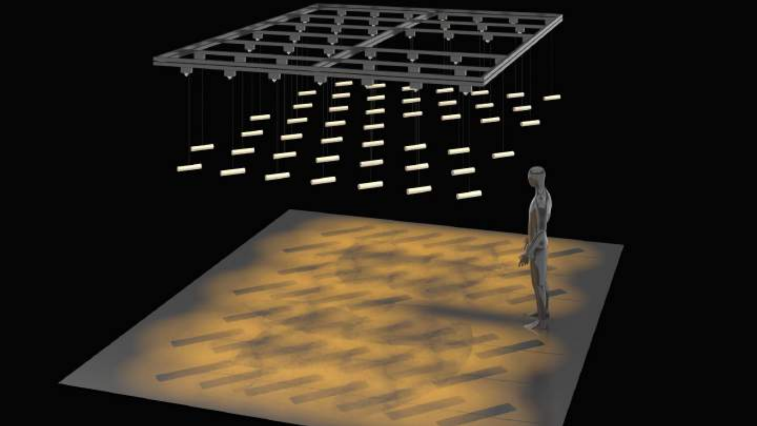
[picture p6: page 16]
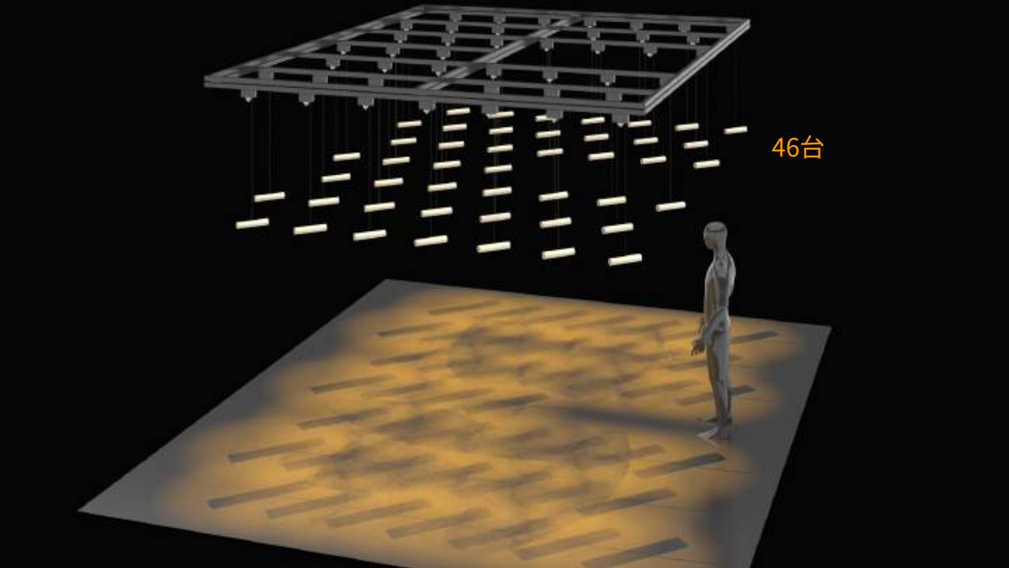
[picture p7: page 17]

46台

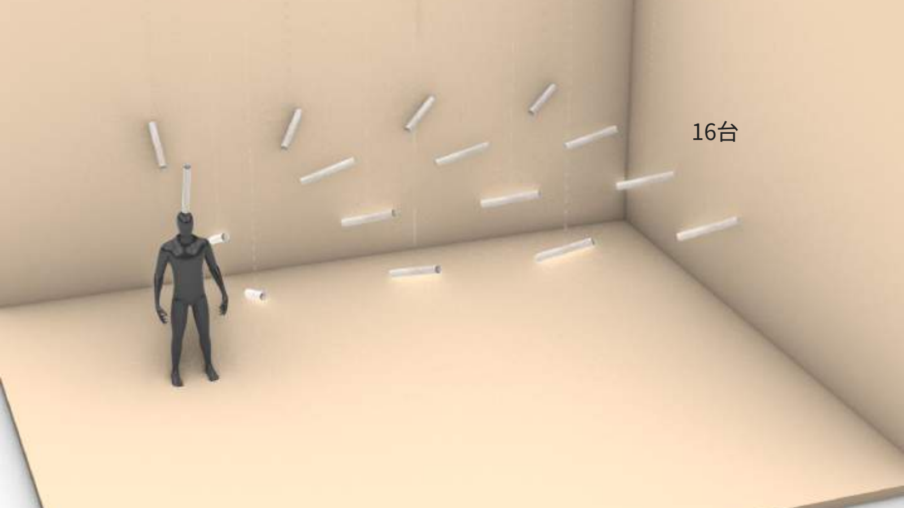
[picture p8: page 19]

16台

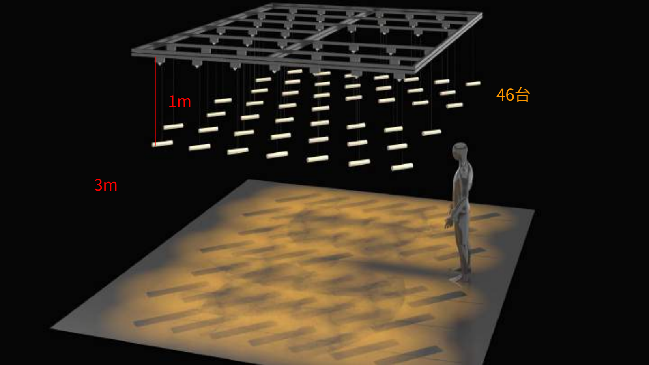
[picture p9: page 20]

3m

1m | 46台

配置

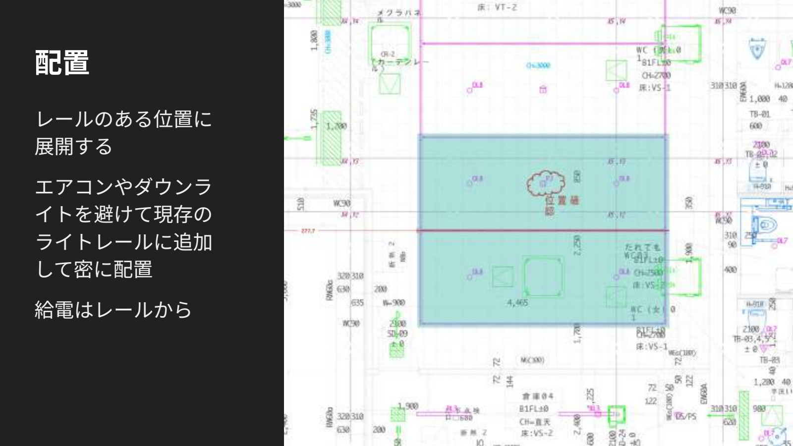
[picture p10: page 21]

レールのある位置に
展開する

エアコンやダウンラ
イトを避けて現存の
ライトレールに追加
して密に配置

給電はレールから

⼨法

46台の場合

⼨法

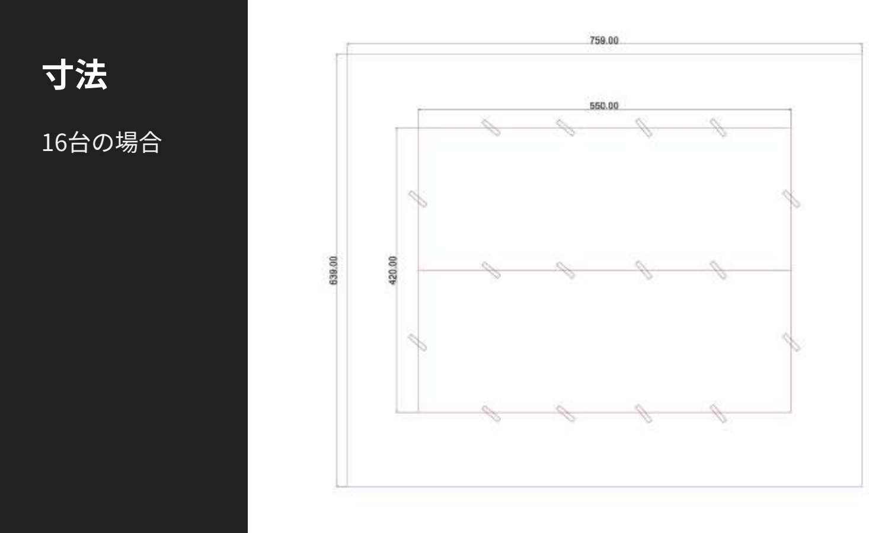
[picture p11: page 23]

16台の場合

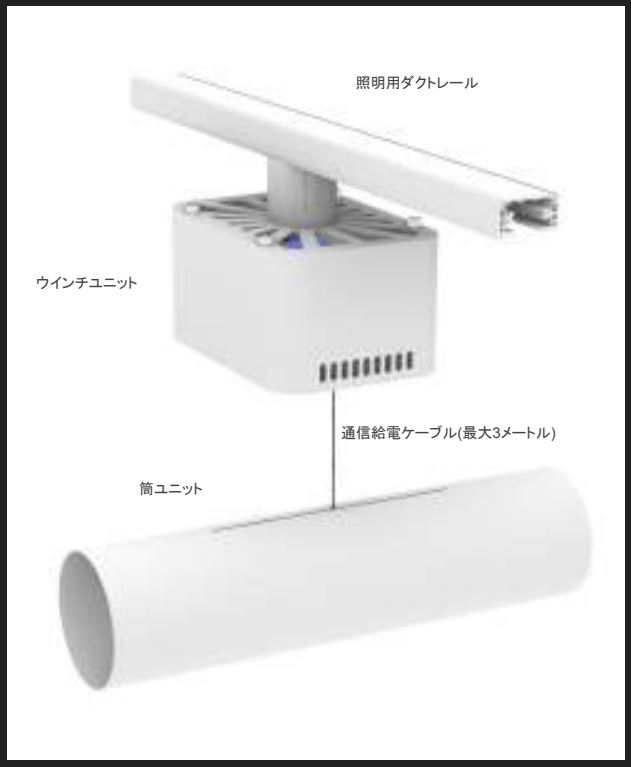
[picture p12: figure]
ウインチユニット; 照明用ダクトレール; 筒ユニット; 通信給電ケーブル(最大3メートル)

## ロボット概要

照明⽤ダクトレールに固定されたウインチユニットから通信給 電ケーブルを介して筒ユニットが接続されており、最⼤3メー トル昇降可能な構造を取っている

ウインチユニットによるスポットライト‧昇降機能に加え、 筒ユニットに内蔵された2軸のモーターとセンサーにより、回 転‧傾きの動作を実現している

また、筒ユニットに取り付けられた計48灯の多⾊LEDにより、 任意の発光パターンで点灯することが可能である

更に、筒ユニットには8x8の⾚外線センサーが搭載されてお り、⼈物を検知し、その⽅向に向かせたり背けさせたりといっ たインタラクションを⾏うことも可能である

## ロボット概要(ウインチユニット)

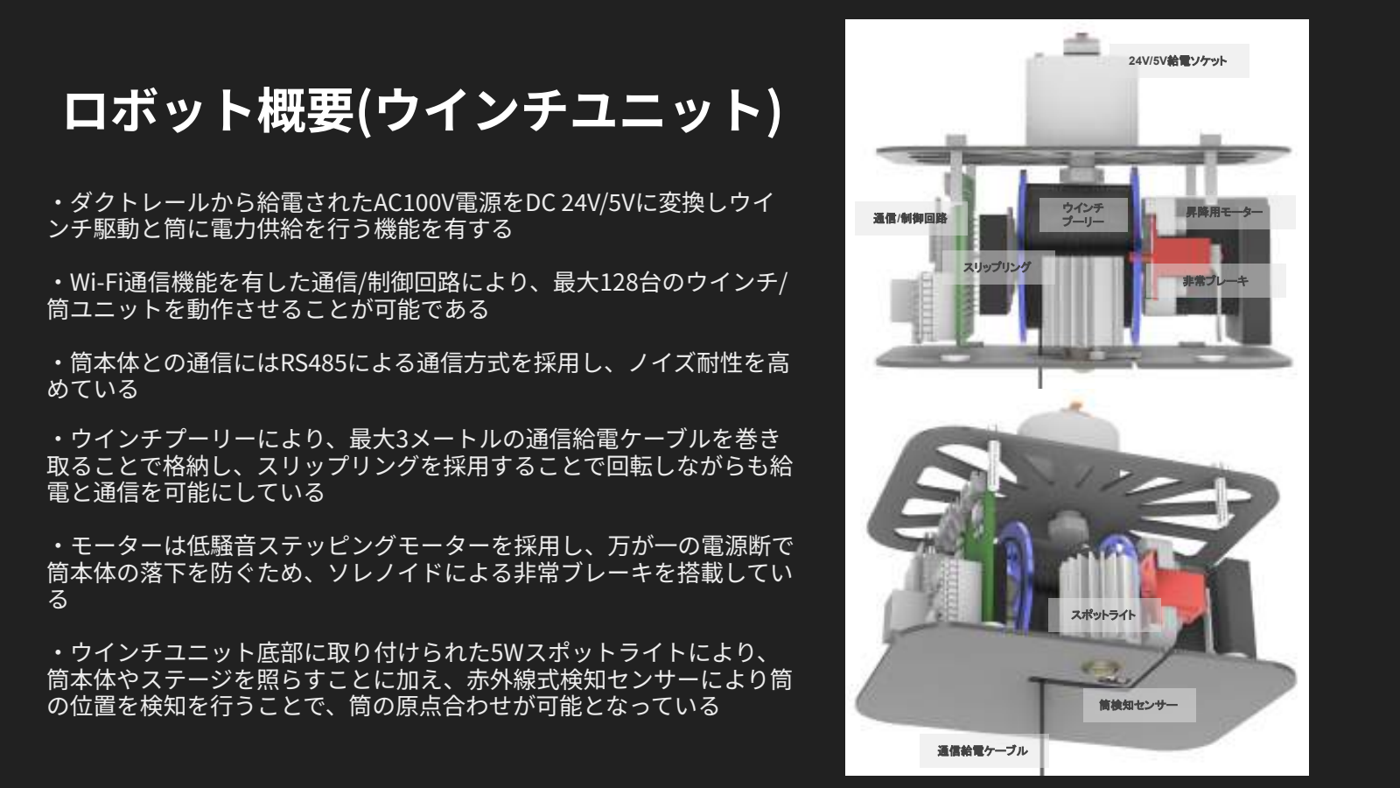
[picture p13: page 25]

‧ダクトレールから給電されたAC100V電源をDC 24V/5Vに変換しウイ ンチ駆動と筒に電⼒供給を⾏う機能を有する

‧Wi-Fi通信機能を有した通信/制御回路により、最⼤128台のウインチ/ 筒ユニットを動作させることが可能である

‧筒本体との通信にはRS485による通信⽅式を採⽤し、ノイズ耐性を⾼ めている

‧ウインチプーリーにより、最⼤3メートルの通信給電ケーブルを巻き 取ることで格納し、スリップリングを採⽤することで回転しながらも給 電と通信を可能にしている

‧モーターは低騒⾳ステッピングモーターを採⽤し、万が⼀の電源断で 筒本体の落下を防ぐため、ソレノイドによる⾮常ブレーキを搭載してい る

‧ウインチユニット底部に取り付けられた5Wスポットライトにより、 筒本体やステージを照らすことに加え、⾚外線式検知センサーにより筒 の位置を検知を⾏うことで、筒の原点合わせが可能となっている

24V/5V給電ソケット

ウインチ | 昇降用モーター 通信/制御回路 | プーリー

スポットライト

筒検知センサー

非常ブレーキ

スリップリング

通信給電ケーブル

## ロボット概要(筒ユニット)

‧スリップリングを組み合わせたコネクタにより、筒ユニットの 連続回転が可能となっている。また、磁⽯コネクタを採⽤するこ とで、万が⼀の故障時に簡単に取り替えることが可能となってい る

‧筒の動作を実現するため、6軸のIMUから得られる3軸の地磁気 と3軸の加速度センサデータを⽤いて、傾き制御モーターにより ±60°回転する機能に加え、フライホイールを搭載した回転制御 モーターにより任意の⾓度への回転が可能となっている

‧筒前⾯に取り付けられた⾚外線マトリクスセンサにより、8x8の 解像度で⼈物や熱源を検知し、その重⼼を検知する機能を有する

‧筒前⾯/背⾯に搭載された24灯多⾊LEDを個別制御することで、 任意のパターンで発光させることが可能となっている

スリップリング式
磁石コネクタ

6軸IMU

赤外線
GridEYE

通信給電ケーブル

24灯多色LED

24灯多色LED

傾き制御モーター

フライホイール式
回転制御モーター
制御回路1 | 制御回路2
筒前面 | 筒背面 6軸IMU

24灯多色LED

24灯多色LED

赤外線
GridEYE

筒接続部

筒接続部

## ロボット動作原理(垂直回転動作)

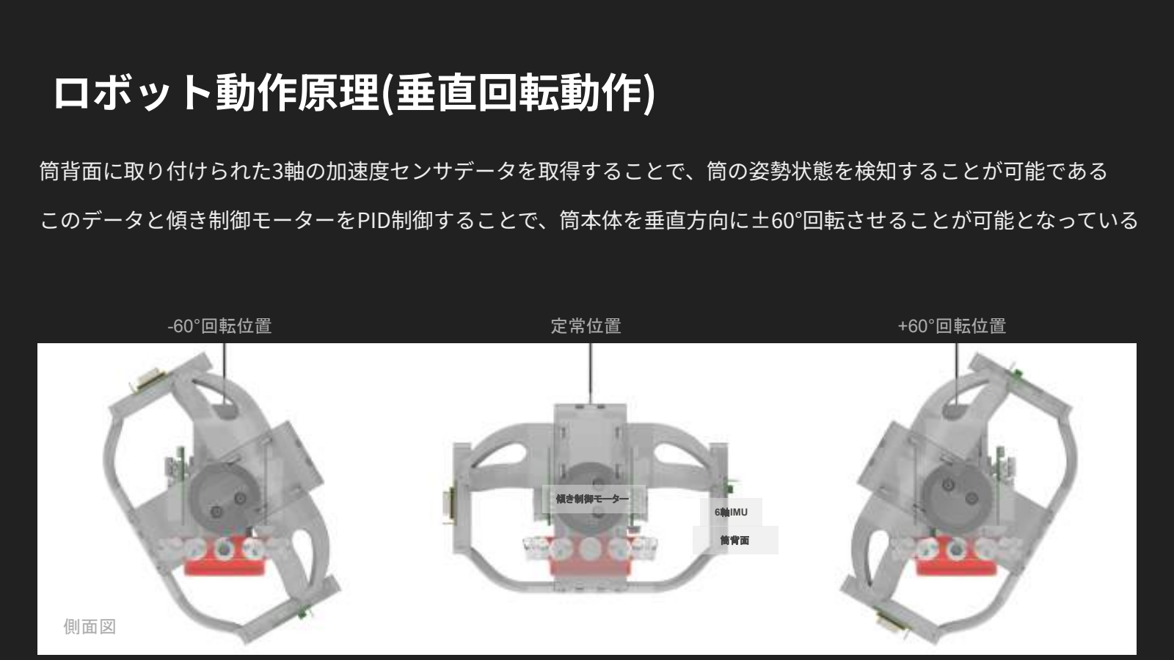
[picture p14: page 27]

-60°回転位置 | 定常位置 | +60°回転位置

6軸IMU

筒背⾯に取り付けられた3軸の加速度センサデータを取得することで、筒の姿勢状態を検知することが可能である

このデータと傾き制御モーターをPID制御することで、筒本体を垂直⽅向に±60°回転させることが可能となっている

筒背面

傾き制御モーター

側面図

## ロボット動作原理(⽔平回転動作)

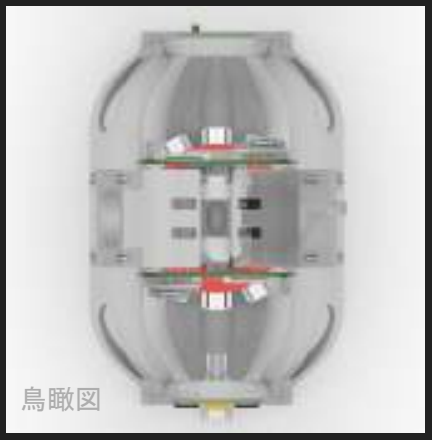
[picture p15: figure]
鳥瞰図
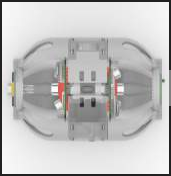
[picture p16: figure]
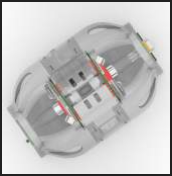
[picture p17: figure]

90°回転位置 | 定常位置 | 210°回転位置

6軸IMU

筒背⾯に取り付けられた3軸の地磁気センサデータを取得することで、筒回転⽅向の絶対座標を検知することが可能である

このデータとフライホイールを搭載した回転制御モーターをPID制御することで、筒本体を⽔平⽅向に±360°回転させることが可能となっている

コネクタに取り付けられたスリップリングにより、給電/通信ケーブルの捻れを考慮することなしに連続回転を実現している

筒背面

## 装置外観

‧ウインチから筒までの⻑さ: 最⼤300cm

‧筒の両端⻑さ: 30cm

‧筒の直径: 76mm

ケーブル長:300cm

両端長さ: 30cm

直径:76mm

## 回路構成

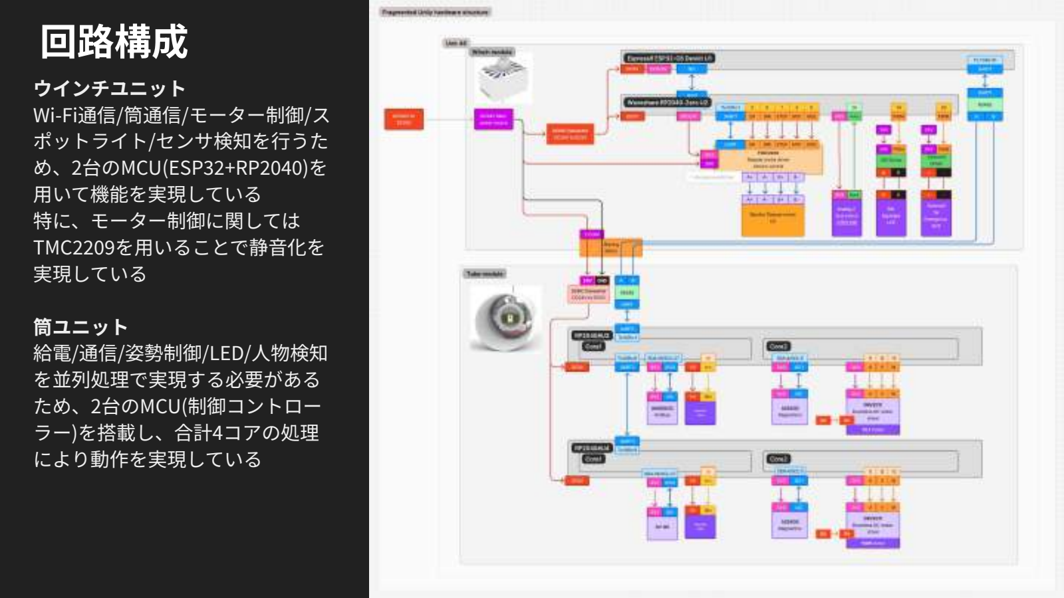
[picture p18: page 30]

ウインチユニット
Wi-Fi通信/筒通信/モーター制御/ス
ポットライト/センサ検知を⾏うた
め、2台のMCU(ESP32+RP2040)を
⽤いて機能を実現している
特に、モーター制御に関しては
TMC2209を⽤いることで静⾳化を
実現している

筒ユニット
給電/通信/姿勢制御/LED/⼈物検知
を並列処理で実現する必要がある
ため、2台のMCU(制御コントロー
ラー)を搭載し、合計4コアの処理
により動作を実現している

- グリッド状に熱源（⼈）をセンシングできるGrid-EYEシステムを天井の9箇所に設置、鑑賞者の平⾯座標を取得
- 空間内の⾳源座標を検出可能なマイクアレイシステムを天井4箇所に設置、物⾳などに反応して座標を取得
- センサ類はRaspberry Piに集約し、Wi-Fi経由メイン制御コンピュータに送信

## 空間センシング

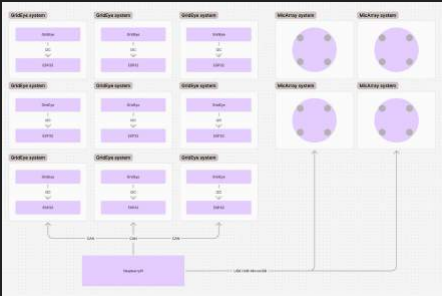
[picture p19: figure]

## 制御システム

メイン制御コンピュータは各ロボットとワイヤレスネットワークで接続。

制御システム → ロボット

鑑賞者の座標、⾳源の座標など

ロボット → 制御システム

システム状態などのフィードバック情報

# 作品体験の流れ

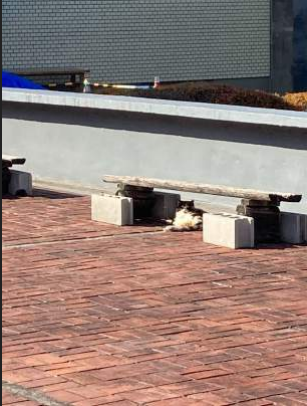
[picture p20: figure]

## ロボットの振る舞い

この円筒形のロボットは、ミニマルな形状な
がらも⽅向を⾃在に変えることで、鑑賞者の
⽅を向いたりそっぽを向いたり、下がってき
たりします。

異種間に⽴ち現れるノンバーバルなコミュニ
ケーションの様式を巧妙になぞり、鑑賞者に
共感や共同意識を芽⽣えさせたり、逆に敵対
する関係性を作り出したりします。

## ロボットの振る舞い

## ロボットの振る舞い

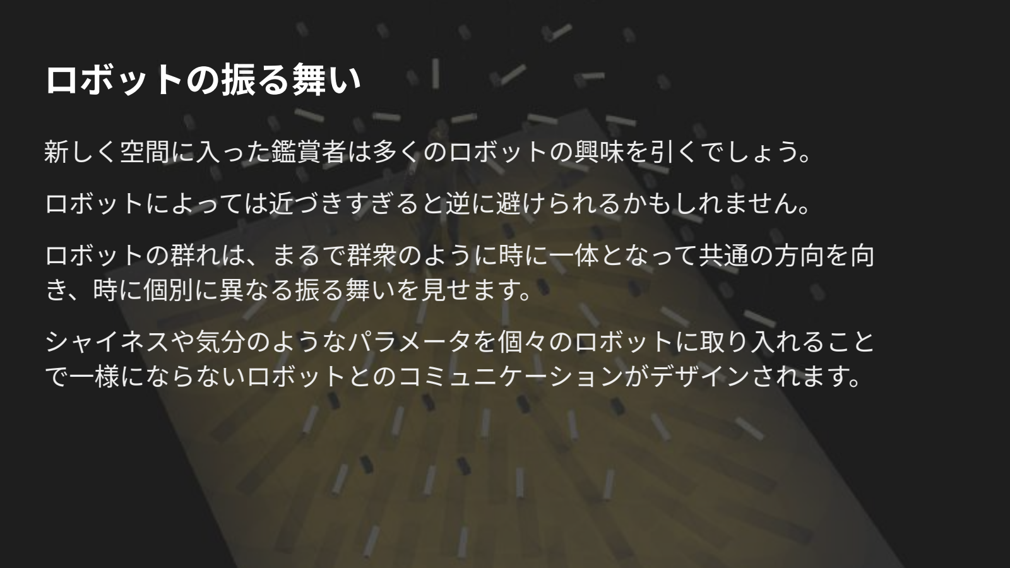
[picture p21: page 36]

新しく空間に⼊った鑑賞者は多くのロボットの興味を引くでしょう。

ロボットによっては近づきすぎると逆に避けられるかもしれません。

ロボットの群れは、まるで群衆のように時に⼀体となって共通の⽅向を向 き、時に個別に異なる振る舞いを⾒せます。

シャイネスや気分のようなパラメータを個々のロボットに取り⼊れること で⼀様にならないロボットとのコミュニケーションがデザインされます。

## ロボットの振る舞い

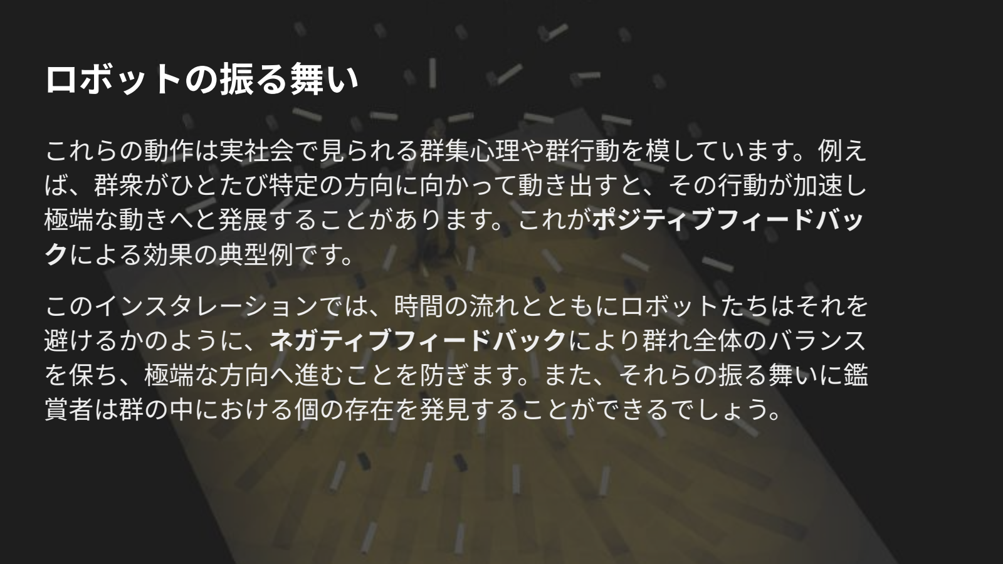
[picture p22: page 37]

これらの動作は実社会で⾒られる群集⼼理や群⾏動を模しています。例え ば、群衆がひとたび特定の⽅向に向かって動き出すと、その⾏動が加速し 極端な動きへと発展することがあります。これがポジティブフィードバッ クによる効果の典型例です。

このインスタレーションでは、時間の流れとともにロボットたちはそれを 避けるかのように、ネガティブフィードバックにより群れ全体のバランス を保ち、極端な⽅向へ進むことを防ぎます。また、それらの振る舞いに鑑 賞者は群の中における個の存在を発⾒することができるでしょう。

## 表情のパターン

向きの制御

- こっち向く
- あっち向く
- ぐるぐる回る
- 速く回る
- 遅く回る

⾼さの制御

- 上に退避
- 下に降臨
- 上下に震える

光

- 単純に明るさ
- ホタル明滅系
- 点滅
- ⾊の違い
- 前後での⾊の違い

## 振る舞いのパターン

- 誰かが展⽰室に⼊ってくると
みんながこっちを向く
- ⾄近距離に近づこうとすると
逃げる
- ⾳に反応して⾳源の⽅を向く
- 危害を加えてこなそうだと割
と近くまで降りてくる。
- 触られたりすると点滅して逃
げる
- ⼈がいないと安⼼して降りて
くる。
- 近くの筒とのコミュニケー
ション
- 伝搬して喧騒へ発展する
ことも

## ⼀度に体験できる⼈数

空間に⼈が⼊るだけ⼊ってもらって⼤丈夫ですが、

⼈が多すぎると筒たちはビビってあんまり降りてこないと思われます。

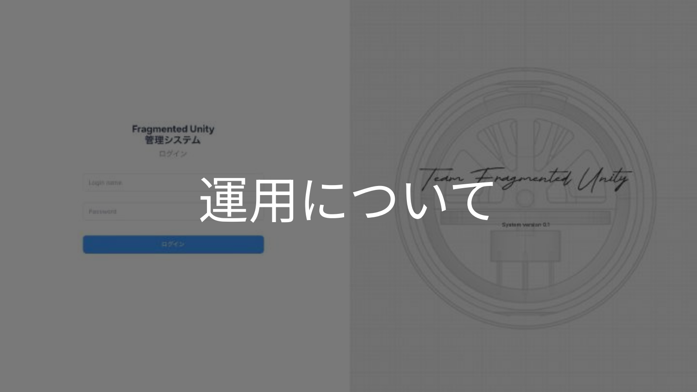
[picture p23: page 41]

# 運⽤について

## デバイス管理システム

ひと⽬で全ロボットの健康
状態を確認できるシステム
を構築。現場のバックヤー
ドからの確認、開発者らも
リモートで確認できるよう
にする。

## モジュール交換システム

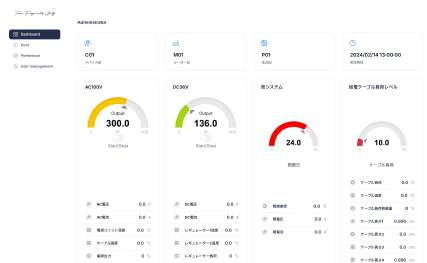
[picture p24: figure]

故障発⽣から修理/交換プロ
セスを現場スタッフでも可
能なように設計する。

故障パーツは配送サービス
を利⽤して、コストの掛か
る現場に出向いてのメンテ
ナンスは最⼩限に留める。

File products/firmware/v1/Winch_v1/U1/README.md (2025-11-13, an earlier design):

# U1 Firmware - ESP32-S3 Winch Controller

**プロジェクト**: FU@ComoNe (Fragmentations of Unity @ Common Nexus)
**バージョン**: v9
**ターゲット**: ESP32-S3-DevKitC-1
**フレームワーク**: Arduino + PlatformIO

---

## 🚀 クイックスタート

### 1. VS Codeでプロジェクトを開く

```bash
cd /path/to/projects/nagoya-tube-installation/firmware/Winch/U1
code .
```

### 2. 開発指示書を確認

**📘 必読**: [.claude/instructions.md](.claude/instructions.md)

このドキュメントに以下が含まれています：
- 開発目的と期限（2025-10-24）
- タスクリスト（Phase 1-5）
- ピンアサイン確認方法
- ファームウェア修正手順
- ビルド・書き込み・テスト手順
- トラブルシューティング

### 3. ファームウェア仕様を確認

**📖 完全仕様**: [U1_FIRMWARE_OVERVIEW.md](U1_FIRMWARE_OVERVIEW.md)

このドキュメントに以下が含まれています：
- システム全体像
- 主要機能（WiFi/MQTT/I2C/UART）
- 通信プロトコル詳細
- LED制御システム
- 状態管理

### 4. ピンアサイン仕様を確認

**🔌 ピンアサイン**: [../../docs/specs/winch-u1-esp32s3-pinout.md](../../docs/specs/winch-u1-esp32s3-pinout.md)

現在確定済みピン：
- GPIO 48: NeoPixel RGB LED (オンボード)
- GPIO 8/9: I2C SDA/SCL (U2 ウィンチモーター)
- GPIO 17/18: UART RX/TX (U3 LED制御)

---

## 🔧 開発環境

### 必要なツール

- **VS Code**: https://code.visualstudio.com/
- **PlatformIO Extension**: VS Code拡張機能
- **ESP32-S3ドライバ**: USB接続用（自動インストール）

### ライブラリ依存

以下は`platformio.ini`で自動インストールされます：

```ini
lib_deps =
    knolleary/PubSubClient@^2.8        # MQTT通信
    adafruit/Adafruit NeoPixel@^1.12.3 # LED制御
```

---

## 📝 主要タスク

### Phase 1: ピンアサイン確定 ✅

- [ ] 基板回路図確認（EasyEDA/KiCad）
- [ ] 実物基板で導通確認
- [ ] `winch-u1-esp32s3-pinout.md` 更新

### Phase 2: ファームウェア修正 ⏳

- [ ] `main.cpp`: GPIO番号定義更新
- [ ] `main.cpp`: I2C/UART初期化確認
- [ ] `platformio.ini`: ビルド設定確認

### Phase 3: ビルド＆書き込み ⏳

```bash
# ビルド
pio run

# 書き込み
pio run --target upload

# シリアルモニター
pio device monitor
```

### Phase 4: 通信テスト ⏳

- [ ] I2C通信テスト (U1 ↔ U2)
- [ ] UART通信テスト (U1 → U3)
- [ ] システム統合テスト

### Phase 5: ドキュメント更新 ⏳

- [ ] `winch-u1-esp32s3-pinout.md` 更新
- [ ] `../../TODO.md` 更新
- [ ] TODO集約実行

---

## 🧪 テストコマンド例

### I2C通信テスト

```cpp
// ホーミング状態読み取り
Wire.requestFrom(0x08, 2);
char tag = Wire.read();      // 'H'
int status = Wire.read();    // 0 or 1

// 位置制御（1000mm）
Wire.beginTransmission(0x08);
Wire.write('Z');
Wire.write(0xE8);  // LSB
Wire.write(0x03);  // MSB
Wire.endTransmission();
```

### UART通信テスト

```cpp
// 統合データパケット（赤色LED）
Serial1.printf("DATA,F,255,0,0,R,0,0,0,P,0.00,0.00,B,0,H,0.00\n");

// Sparkコマンド（10秒）
Serial1.printf("SPARK,10\n");

// クリア
Serial1.printf("C\n");
```

---

## 📂 プロジェクト構造

```
U1/
├── .claude/
│   ├── instructions.md       # 開発指示書（最重要）
│   └── claude_config.json    # Claude設定
├── .vscode/
│   └── settings.json         # VS Code設定
├── src/
│   ├── main.cpp              # メインロジック
│   ├── mqttClient.cpp        # MQTT通信
│   ├── otaUpdater.cpp        # OTA更新
│   └── globals.h             # グローバル変数
├── platformio.ini            # PlatformIO設定
├── U1_FIRMWARE_OVERVIEW.md   # ファームウェア完全仕様
└── README.md                 # このファイル
```

---

## 🔗 関連ドキュメント

| ドキュメント | 説明 |
|---|---|
| [.claude/instructions.md](.claude/instructions.md) | **開発指示書（最重要）** |
| [U1_FIRMWARE_OVERVIEW.md](U1_FIRMWARE_OVERVIEW.md) | ファームウェア完全仕様 |
| [../../docs/specs/winch-u1-esp32s3-pinout.md](../../docs/specs/winch-u1-esp32s3-pinout.md) | ピンアサイン仕様 |
| [../../docs/specs/winch-circuit-design.md](../../docs/specs/winch-circuit-design.md) | Winch V2回路設計 |
| [../../notes/v1-analysis.md](../../notes/v1-analysis.md) | V1システム分析 |
| [../../TODO.md](../../TODO.md) | プロジェクト全体TODO |

---

## 📞 サポート

### 質問・問題が発生した場合

1. **[.claude/instructions.md](.claude/instructions.md)** のトラブルシューティングセクションを確認
2. **[U1_FIRMWARE_OVERVIEW.md](U1_FIRMWARE_OVERVIEW.md)** で該当機能の仕様を確認
3. シリアルモニター出力を保存してサポートに共有

---

## ⚠️ 重要な注意事項

- **期限**: 2025-10-24（基板発注締切）
- **I2Cプルアップ抵抗必須**: 4.7kΩ推奨
- **WiFi/MQTT必須**: 起動にはネットワーク接続が必要
- **ホーミング完了待ち**: 制御コマンドはホーミング完了後のみ有効
- **デバイスID取得必須**: MQTT経由でID取得後に本格動作

---

## ✅ 完了基準

- [ ] ピンアサイン確定・ドキュメント更新
- [ ] ファームウェア修正完了
- [ ] ビルド成功
- [ ] ESP32-S3への書き込み成功
- [ ] I2C通信テスト成功
- [ ] UART通信テスト成功
- [ ] システム統合テスト成功
- [ ] TODO.md更新・集約

**すべて完了したら基板発注準備完了！🎉**

---

**開発を開始してください。VS Codeでこのディレクトリを開き、`.claude/instructions.md`を確認してから作業を始めてください。**

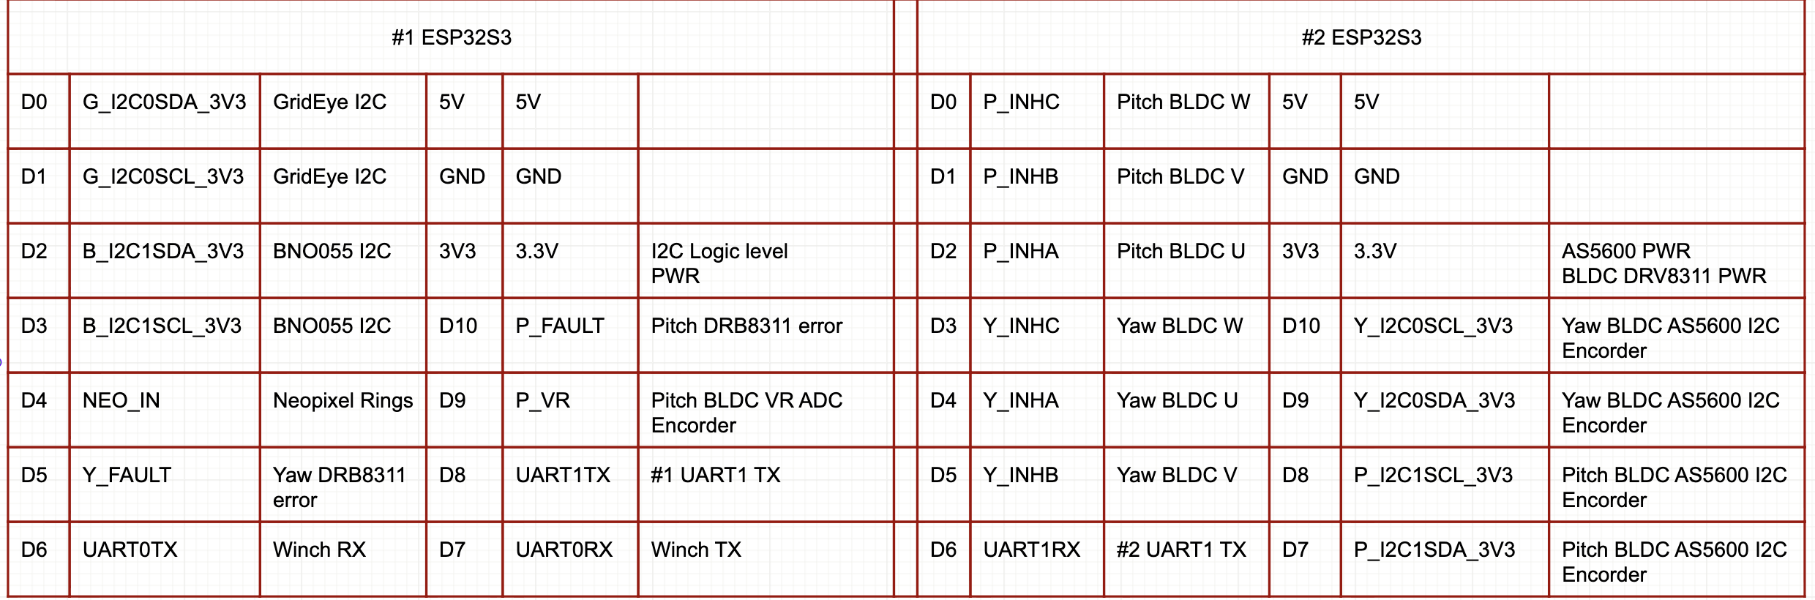
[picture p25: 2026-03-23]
products/firmware/v2/Tube_v2/Specs/images/Unit1-2 circuit.png

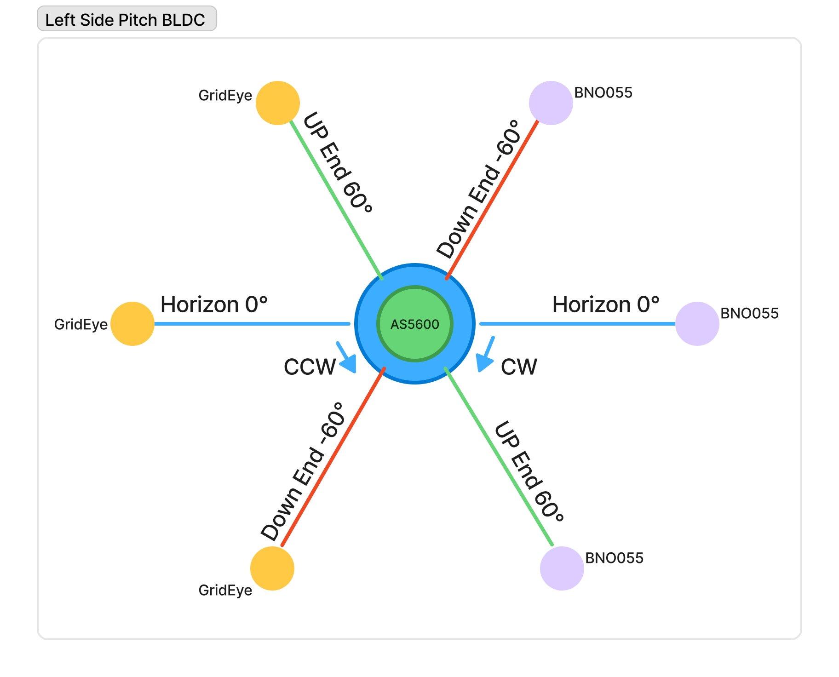
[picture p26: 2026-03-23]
products/firmware/v2/Tube_v2/Specs/images/LeftSideTubePitchBLDC.png

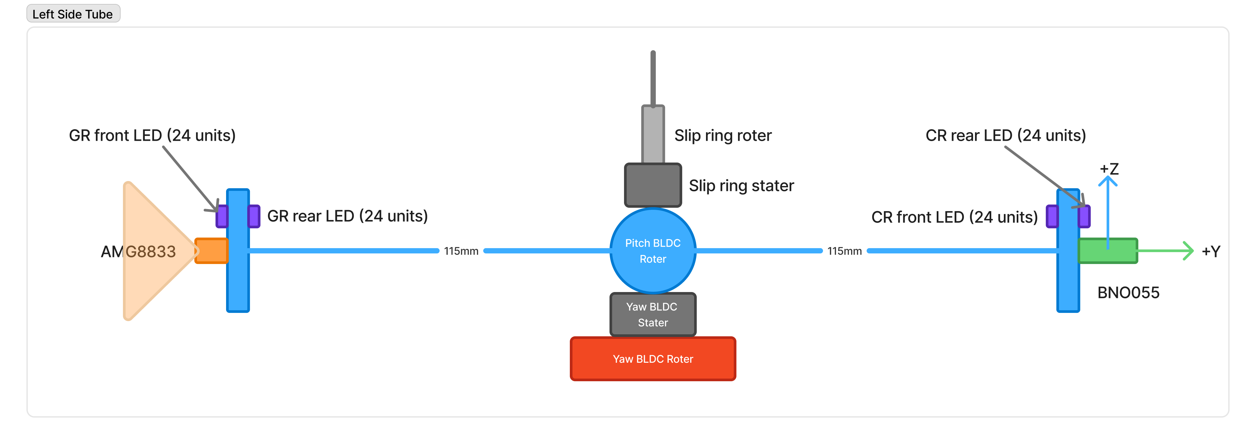
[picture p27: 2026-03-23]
products/firmware/v2/Tube_v2/Specs/images/LeftSideTube.png

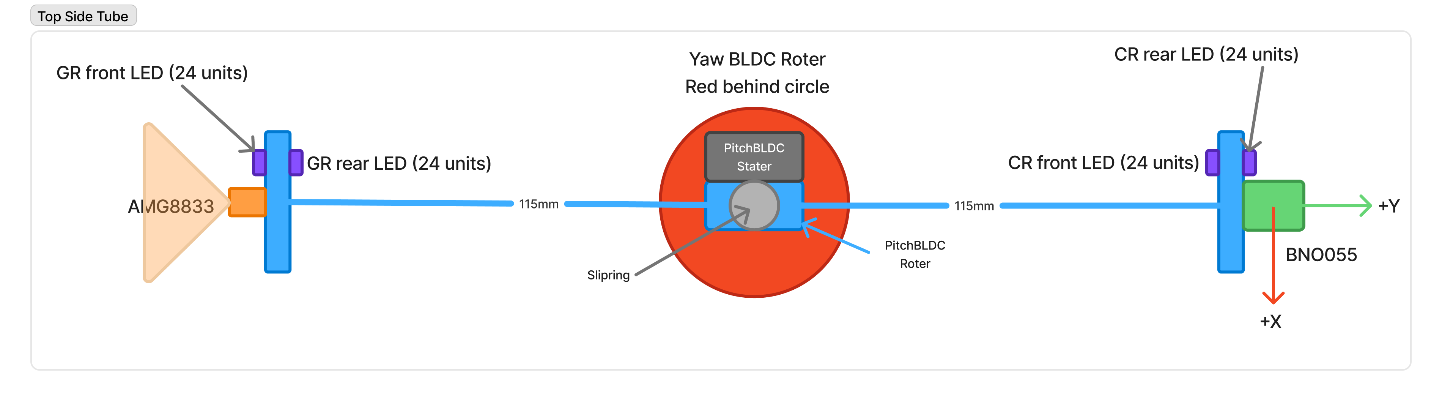
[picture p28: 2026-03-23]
products/firmware/v2/Tube_v2/Specs/images/TopSideTube.png

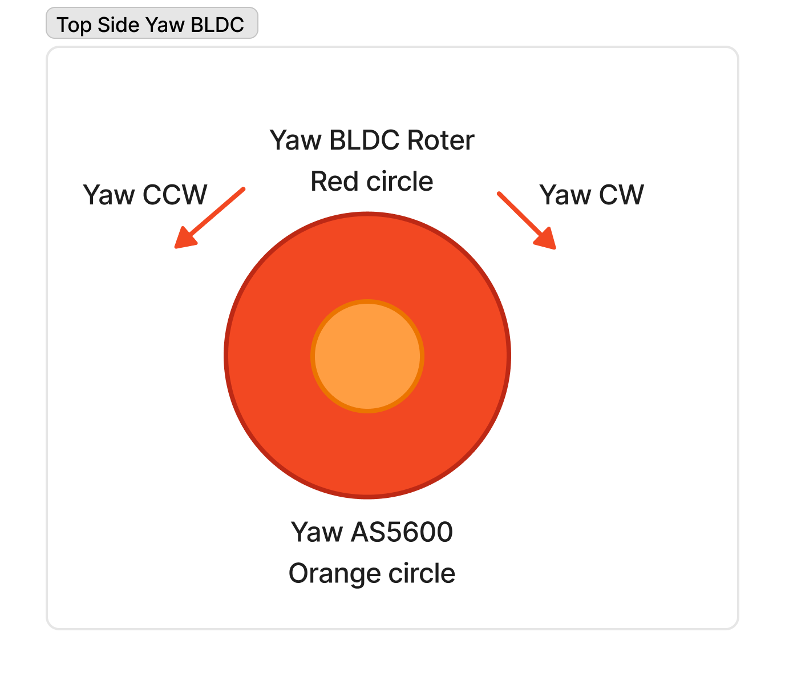
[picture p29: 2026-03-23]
products/firmware/v2/Tube_v2/Specs/images/TopSideTubeYawBLDC.png

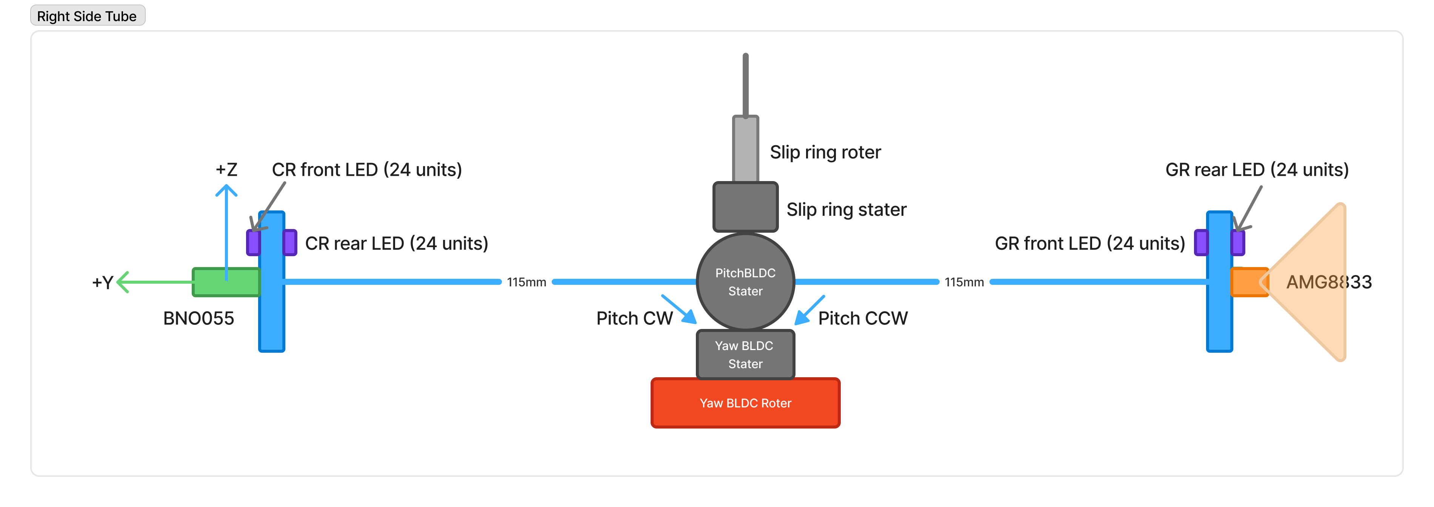
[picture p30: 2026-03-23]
products/firmware/v2/Tube_v2/Specs/images/RightSideTube.png

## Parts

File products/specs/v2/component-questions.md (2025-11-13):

# V2 Component仕様書作成 - 質問リスト

**作成日**: 2025-11-09
**ステータス**: 🔄 回答待ち

---

## 回答方法

各質問番号の下に回答を記載してください。
不明な項目は「未定」「V1と同じ」「要検討」等でも構いません。

---

## 電子部品

### 1. ESP32-S3

**Q1-1: ESP32-S3の具体的な型番は？**
- 例: ESP32-S3-WROOM-1, ESP32-S3-WROOM-1-N8R2, ESP32-S3-DevKitC-1
- 回答:- ESP32‑S3‑MINI‑1‑N8

**Q1-2: WiFi/Bluetoothアンテナの種類は？**
- 選択肢: PCBアンテナ / 外付けアンテナ / チップアンテナ
- 回答:チップアンテナ

**Q1-3: Flashメモリサイズは？**
- 選択肢: 4MB / 8MB / 16MB / 32MB
- 回答:8MB

**Q1-4: PSRAMサイズは？**
- 選択肢: なし / 2MB / 8MB
- 回答:なし

**Q1-5: GPIO割当の方針は？**
- I2C0 (SDA/SCL): GPIOピン番号
- I2C1 (SDA/SCL): GPIOピン番号
- UART (TX/RX): GPIOピン番号
- PWM (サーボ): GPIOピン番号
- NeoPixel Data: GPIOピン番号
- 回答:未定

---

### 2. AS5600

**Q2-1: 磁石の仕様は？**
- 直径:4mm
- 厚さ:3mm
- 磁束密度:不明

**Q2-2: センサーと磁石の距離は？**
- 推奨範囲: 0.5-3mm
- 実装想定距離:
- 回答:1mm

**Q2-3: I2Cアドレスは？**
- デフォルト: 0x36
- 変更の必要性:なし

---

### 3. GridEye (AMG8833)

**Q3-1: 使用温度範囲は？**
- 選択肢: 0-80℃ / -20-80℃
- 回答:0-80℃

**Q3-2: フレームレートは？**
- 選択肢: 1fps / 10fps
- 回答:10fps

**Q3-3: I2Cアドレスは？**
- 選択肢: 0x68 / 0x69
- 回答:0x68
Q3-4: 購入先は?
	回答: https://akizukidenshi.com/catalog/g/g116737/

---

### 4. GY-85

**Q4-1: GY-85の構成センサーは確定？**
- 想定: ADXL345 (加速度) + ITG3205 (ジャイロ) + HMC5883L (磁気)
- 回答:HMC5883LはQMC5883Lに変更

**Q4-2: I2Cアドレス競合の対策は？**
- 複数センサーでアドレス重複の可能性
- 対策方針:アドレス重複は解決済み
- 回答:アドレスは/Users/kyopan/Dropbox (個人)/Obsidian/kyopan/projects/fu/products/firmware/v1/Tube_v1/FU_TUBE_RP2040_U4/FU_TUBE_RP2040_U4.inoを参照

**Q4-3: 磁気センサー較正方法は？**
- 較正タイミング:
- 較正方法:
- 回答:使用しない

---

### 5. NeoPixel WS2812B

**Q5-1: LEDの型番は？**
- 選択肢: WS2812B / SK6812 / その他
- 回答:WS2812B 2020

**Q5-2: 1個あたりの最大電流は？**
- 通常: 60mA (RGB全点灯時)
- 想定輝度での電流:
- 回答:18mA

**Q5-3: データ線のレベルシフターは必要？**
- NeoPixelは5V信号推奨、ESP32は3.3V出力
- レベルシフター使用の有無:
- 回答:電源は5Vだがデータ線は3.3VでOK

---

### 6. DCDC Converter

**Q6-1: 採用候補の優先順位は？**
- 候補: LM2596 / MP1584 / XL4015
- 優先順位:
- 回答:TPS54202DDCR

**Q6-2: 出力電流の安全マージンは？**
- 2A出力に対する実負荷想定:
- 安全マージン:
- 回答:1.5倍

**Q6-3: スイッチング周波数は？**
- ノイズ対策の観点から:
- 回答:500kHz

---

## モーター・アクチュエーター

### 7. DS-M005 Servo

**Q7-1: サーボの購入先/型番確認は？**
- DS-M005で確定？
- 回答:次のステップでDevboardでテストしたい

**Q7-2: 動作電圧は5V固定？**
- 範囲: 4.8-6V
- 推奨電圧:
- 回答:3.7~4.2v dc

**Q7-3: PWM周波数は50Hz固定？**
- 一部サーボは333Hz対応
- 回答:一般的なRCサーボと同等

---

### 8. BLDC YAW Motor

**Q8-1: モーターの型番は？**
- V1と同じ？
- 回答:V1と同じ

**Q8-2: KV値（RPM/V）は？**
- 回答:330

**Q8-3: 定格電圧・電流は？**
- 電圧:5V
- 電流:1A
- 抵抗: 6.5Ω

**Q8-4: SimpleFOCのドライバICは？**
- 選択肢: DRV8313 / L6234 / その他
- 回答:DRV8311

**Q8-5: エンコーダーポールペア数は？**
- 回答:7極

---

## 機構部品

### 9. SlipRing

**Q9-1: スリップリングの型番/製品名は？**
- 回答:https://www.senring.com SNM012 C type 6Wire

**Q9-2: 定格電流は？**
- 24V系統での電流容量:
- 回答:1.5A

**Q9-3: 回転速度制限は？**
- 最大RPM:
- 回答:150RPM

**Q9-4: 導通抵抗は？**
- 回答:10mΩ

---

### 10. Cable-4pole

**Q10-1: ケーブル長は？**
- 回答:3m

**Q10-2: ケーブル太さ（AWG）は？**
- 24V/TX/RXの電流容量から:
- 回答:AWG 30

**Q10-3: シールドの有無は？**
- UART通信ノイズ対策:
- 回答: 無し

---

### 11. Pulley

**Q11-1: プーリー直径は？**
- 回答: 120mm

**Q11-2: ケーブル巻取り方式は？**
- 選択肢: スプール / ドラム / その他
- 回答: ディスクスプール

**Q11-3: Winch側のケーブル長は？**
- 回答: 質問の意図を確認

---

## 基板・実装

### 12. HD Board

**Q12-1: 基板サイズの制約は？**
- 直径:50~65mm
- 厚さ:1.6mm

**Q12-2: 基板層数は？**
- 選択肢: 2層 / 4層
- 回答:4層

**Q12-3: サーボの実装位置（基板の上面/下面/中央/端）の方針は？**
- 回答:HDの右端。左端はどうしよう。

---

### 13. GR Board / CR Board

**Q13-1: V1基板をそのまま流用？それとも再設計？**
- 回答:V2として既に設計済 (データ共有場所作って)

**Q13-2: 基板サイズ・形状は？**
- 回答:V2として既に設計済 (データ共有場所作って)

**Q13-3: NeoPixelの配置パターンは？**
- 選択肢: 円形 / 直線 / その他
- 回答:裏表に円形上に配置

---

### 14. PR Mount

**Q14-1: 配線方法の方針は？**
- 選択肢: フレキシブル基板 / ハーネス / 直付け
- 回答: FPCかな〜

**Q14-2: コネクタ使用の場合、型番候補は？**
- 回答:AFA07-S10FCC-00

---

## 通信・配線

### 15. I2C Interface

**Q15-1: I2Cクロック周波数は？**
- 選択肢: 100kHz (標準) / 400kHz (高速) / 1MHz
- 回答: 100kHz

**Q15-2: プルアップ抵抗値は？**
- 選択肢: 2.2kΩ / 4.7kΩ / 10kΩ
- 回答: ESP32 S3内部生成

**Q15-3: バス長の最大値は？**
- ケーブル長によるキャパシタンス影響:
- 回答: 最大15cm程度

---

### 16. UART Protocol

**Q16-1: UARTのフロー制御は？**
- 選択肢: なし / RTS-CTS / その他
- 回答:なし

**Q16-2: エラー検出方式は？**
- 選択肢: CRC / チェックサム / パリティ / なし
- 回答: CRC/パリティ

**Q16-3: バッファサイズは？**
- 回答:未定

---

### 17. NeoPixel Signal

**Q17-1: 信号線の最大長は？**
- HD→GR→CRの総距離:
- 回答:30cm

**Q17-2: データ線バッファICは使用？**
- 例: 74HCT245等
- 回答:不使用

**Q17-3: リフレッシュレートは？**
- fps:400kHz

---

## 回答完了後

全ての回答が完了したら、このファイルを保存し、CICに確認を依頼してください。

---

## 変更履歴

| 日付 | 変更内容 | 担当 |
|---|---|---|
| 2025-11-09 | 質問リスト初版作成 | CIC |

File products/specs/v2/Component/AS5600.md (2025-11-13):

# AS5600 磁気エンコーダー仕様書

**作成日**: 2025-11-09
**ステータス**: ✅ 確定

---

## 基本仕様

| 項目 | 仕様 |
|---|---|
| **型番** | AS5600 |
| **タイプ** | 12-bit磁気ロータリーポジションセンサー |
| **分解能** | 12-bit (4096段階) |
| **角度範囲** | 0-360° (連続回転対応) |
| **インターフェース** | I2C |
| **I2Cアドレス** | 0x36 (固定) |
| **動作電圧** | 3.0-5.5V |
| **消費電流** | 6.5mA (typ.) |

---

## 使用箇所

### AS-S (Slip Ring Encoder)

| 項目 | 仕様 |
|---|---|
| **配置場所** | スリップリング上部（4極ミニプラグ メス側） |
| **測定対象** | ケーブル相対回転角度 |
| **用途** | ケーブルねじれ検出 → YAWモーター補正 |
| **接続先** | ESP32-S3 #2 (I2C) |

### AS-Y (YAW Encoder)

| 項目 | 仕様 |
|---|---|
| **配置場所** | YAWモーター軸 |
| **測定対象** | YAWモーター回転角度 |
| **用途** | SimpleFOC制御フィードバック |
| **接続先** | ESP32-S3 #2 (I2C) |

**合計使用数**: 2個

---

## 磁石仕様

| 項目 | 仕様 |
|---|---|
| **直径** | 4mm |
| **厚さ** | 3mm |
| **材質** | ネオジム磁石（推定） |
| **磁束密度** | 不明（測定予定） |
| **推奨磁束密度** | 50-100mT |

---

## 機械的配置

| 項目 | 仕様 |
|---|---|
| **センサー-磁石距離** | 1mm |
| **推奨距離範囲** | 0.5-3mm |
| **配置精度** | 同軸ずれ: ±0.5mm以内 |
| **取付方法** | 基板実装 |

---

## I2C通信仕様

| 項目 | 仕様 |
|---|---|
| **I2Cアドレス** | 0x36 (変更不要) |
| **クロック周波数** | 100kHz |
| **プルアップ抵抗** | ESP32-S3内部プルアップ使用 |
| **バス長** | 最大15cm程度 |

**アドレス競合対策:**
- AS-S (0x36) と AS-Y (0x36) は**別々のI2Cバス**に接続
- ESP32-S3 #2 で2系統のI2Cを使用

---

## 制御ロジック

### AS-S (ケーブルねじれ検出)

```cpp
// ケーブル角度読取
uint16_t cable_angle = AS5600_ReadAngle(AS_S_ADDRESS);

// ねじれ補正判定
if (abs(cable_angle - 180) > THRESHOLD) {
  // YAWモーター逆回転でケーブル巻き戻し
  apply_yaw_correction(cable_angle);
}
```

### AS-Y (YAWモーターフィードバック)

```cpp
// SimpleFOC用エンコーダー値
float yaw_angle = AS5600_ReadAngle(AS_Y_ADDRESS) * (360.0 / 4096.0);
motor.move(target_angle);
```

---

## レジスタマップ（主要）

| レジスタ | アドレス | 用途 |
|---|---|---|
| **RAW ANGLE** | 0x0C-0x0D | 生角度値 (0-4095) |
| **ANGLE** | 0x0E-0x0F | フィルタ後角度値 |
| **STATUS** | 0x0B | 磁石検出状態 |
| **AGC** | 0x1A | 自動ゲイン制御 |

---

## キャリブレーション

| 項目 | 方法 |
|---|---|
| **磁石検出確認** | STATUS レジスタ確認 |
| **ゼロ点設定** | ソフトウェアでオフセット補正 |
| **較正不要** | ハードウェア較正なし（工場出荷時設定） |

---

## 参考資料

- [AS5600 Datasheet](https://ams.com/documents/20143/36005/AS5600_DS000365_5-00.pdf)
- [AS5600 Application Note](https://ams.com/documents/20143/36005/AS5600_AN000365_1-00.pdf)

---

## 決定事項

- [x] 磁石サイズ: 4mm × 3mm
- [x] センサー-磁石距離: 1mm
- [x] I2Cアドレス: 0x36 (変更なし)
- [ ] 磁石磁束密度測定
- [ ] AS-S/AS-Y の I2Cバス割当確定

---

## 変更履歴

| 日付 | 変更内容 | 担当 |
|---|---|---|
| 2025-11-09 | 初版作成 | CIC |

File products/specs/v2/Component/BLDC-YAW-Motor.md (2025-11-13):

# BLDC YAW Motor 仕様書

**作成日**: 2025-11-09
**ステータス**: ✅ V1と同等

---

## 基本仕様

| 項目 | 仕様 |
|---|---|
| **型番** | V1と同じ（型番未記載） |
| **タイプ** | ブラシレスDCモーター (BLDC) |
| **KV値** | 330 RPM/V |
| **定格電圧** | 5V |
| **定格電流** | 1A |
| **抵抗** | 6.5Ω |
| **極数** | 7極 (ポールペア数) |

---

## 配置

| 項目 | 仕様 |
|---|---|
| **実装位置** | HD (Horozon Disc) 下部 |
| **回転軸** | YAW軸（水平回転） |
| **用途** | HD全体の水平回転 / ケーブルねじれ補正 |
| **エンコーダー** | AS5600 (AS-Y) |

---

## 制御方式

### SimpleFOC制御

| 項目 | 仕様 |
|---|---|
| **制御IC** | DRV8311 |
| **制御方式** | Field Oriented Control (FOC) |
| **制御Core** | ESP32-S3 #2 Core 0 |
| **フィードバック** | AS5600 エンコーダー (I2C) |
| **ポールペア数** | 7 |

### DRV8311 仕様

| 項目 | 仕様 |
|---|---|
| **型番** | DRV8311 |
| **メーカー** | Texas Instruments |
| **最大電流** | 2.5A (連続) |
| **動作電圧** | 4.5-40V |
| **制御方式** | 3相ブリッジドライバ |
| **インターフェース** | SPI (設定用) |

---

## 電気特性

### 電圧-回転数特性

| 電圧 | 回転数 (理論値) |
|---|---|
| 3.7V | 1,221 RPM |
| 5V | 1,650 RPM |
| 7.4V | 2,442 RPM |

**計算式:**
```
RPM = KV値 × 電圧
    = 330 RPM/V × 5V
    = 1,650 RPM
```

### 電流-トルク特性

| 項目 | 値 |
|---|-----|
| **定格電流** | 1A |
| **最大電流** | 2.5A (DRV8311制限) |
| **抵抗** | 6.5Ω |
| **電圧降下** | 1A × 6.5Ω = 6.5V |

---

## SimpleFOC制御パラメータ

### 基本設定

```cpp
// モーター設定
BLDCMotor motor = BLDCMotor(7); // 7極

// ドライバ設定
BLDCDriver3PWM driver = BLDCDriver3PWM(PWM_A, PWM_B, PWM_C, EN);

// エンコーダー設定
AS5600Encoder encoder = AS5600Encoder(0x36); // AS-Y

// FOC設定
motor.linkSensor(&encoder);
motor.linkDriver(&driver);

// 制御パラメータ
motor.voltage_power_supply = 5.0;
motor.voltage_limit = 5.0;
motor.velocity_limit = 100; // rad/s
motor.foc_modulation = FOCModulationType::SpaceVectorPWM;
motor.torque_controller = TorqueControlType::voltage;
motor.controller = MotionControlType::velocity;

// PIDパラメータ（要調整）
motor.PID_velocity.P = 0.2;
motor.PID_velocity.I = 0.0;
motor.PID_velocity.D = 0.0;
```

### 制御ループ

```cpp
void loop() {
  // エンコーダー読取
  encoder.update();

  // FOC制御
  motor.loopFOC();
  motor.move(target_velocity);

  // ケーブルねじれ補正
  if (cable_twist_detected()) {
    motor.move(-target_velocity); // 逆回転
  }
}
```

---

## ケーブルねじれ補正ロジック

```cpp
// AS-S (スリップリング角度) 読取
uint16_t cable_angle = AS5600_Read(AS_S_ADDRESS);

// ねじれ判定（±90°以上）
if (abs(cable_angle - 180) > 90) {
  // YAW逆回転でケーブル巻き戻し
  float correction_speed = calculate_correction(cable_angle);
  motor.move(-correction_speed);
} else {
  // 通常YAW制御
  motor.move(target_velocity);
}
```

---

## 電源仕様

| 項目 | 仕様 |
|---|---|
| **供給電圧** | 5V (DCDC出力) |
| **動作電流** | 1A (定格) |
| **最大電流** | 2.5A (DRV8311制限) |
| **電源系統** | DCDC 5V出力 |

---

## 機構設計

| 項目 | 仕様 |
|---|---|
| **取付位置** | HD下部中央 |
| **取付方法** | ネジ固定 or クランプ固定 |
| **回転軸方向** | 垂直（YAW軸） |

**決定事項:**
- [ ] モーター取付構造設計
- [ ] エンコーダー磁石取付位置
- [ ] 配線経路設計

---

## 参考資料

- [DRV8311 Datasheet](https://www.ti.com/lit/ds/symlink/drv8311.pdf)
- [SimpleFOC Library](https://simplefoc.com/)
- [V1 ファームウェア参照](../../firmware/v1/)

---

## 決定事項

- [x] モーター型番: V1と同じ
- [x] KV値: 330 RPM/V
- [x] 定格電圧・電流: 5V / 1A
- [x] ドライバIC: DRV8311
- [x] ポールペア数: 7極
- [ ] PIDパラメータ調整
- [ ] 機構設計確定

---

## 変更履歴

| 日付 | 変更内容 | 担当 |
|---|---|---|
| 2025-11-09 | 初版作成（V1仕様継承） | CIC |

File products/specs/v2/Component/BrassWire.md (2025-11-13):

# 真鍮線 仕様書

**作成日**: 2025-11-09
**ステータス**: ✅ 確定

---

## 基本仕様

| 項目 | 仕様 |
|---|---|
| **製品名** | 黄銅線(塩ビ管入り) |
| **型番** | 4940372013177 |
| **材質** | 真鍮（黄銅） |
| **線径** | 1.0mm |
| **長さ** | 300mm/本 |
| **入数** | 20本/パック |
| **使用本数** | 6本（PR固定用） |
| **価格** | ￥1,100（税込、20本入） |

---

## 製品情報

**メーカー**: Eggs Store

**商品ページ**: https://eggs.bulks.jp/public_html/products/detail/892

**特徴:**
- 塩ビ管に入った直線形状
- 塩ビ管の両端に樹脂製キャップ付属
- 長さ300mmの直線ストレート

---

## 使用目的

**役割**: PR（Pitch Ring）取付機構の固定

**構造:**
```
HD → PR取付機構 → 真鍮線6本 → GR/CR固定
```

**配置:**
- 6本の真鍮線でGR/CRリングをPR取付機構に固定
- 円周方向に等間隔配置（60°間隔想定）
- HD側: PR取付機構に真鍮線固定
- リング側: GR/CR基板に真鍮線固定

---

## 機械的特性

### 真鍮（黄銅）物性

| 項目 | 値 |
|---|-----|
| **密度** | 8.4 g/cm³ |
| **引張強度** | 300-500 MPa |
| **弾性率** | 100-110 GPa |
| **伸び** | 20-40% |
| **融点** | 900-940℃ |

### 1.0mm線の特性

| 項目 | 計算値 |
|---|---|
| **断面積** | π × (0.5mm)² = 0.785 mm² |
| **1本あたり引張荷重** | 0.785mm² × 300MPa = 235.5 N ≈ 24 kgf |
| **6本合計** | 1,413 N ≈ 144 kgf |

**安全率:**
- GR/CR重量: 未測定（推定 < 500g）
- 安全率: 144 kgf / 0.5 kgf = **288倍** ✅ 十分

---

## 加工方法

### 必要加工

1. **長さカット**: 300mm → 必要長さ（未決定）
2. **端部処理**: 固定穴への挿入のため端部研磨
3. **曲げ加工**: PR固定構造に応じて曲げ加工の可能性

### 固定方法

**採用方式: はんだ固定**

**PR取付機構側:**
- 真鍮線端部をPR取付機構にはんだ付け
- はんだ接合部の機械的強度を確保
- 固定位置: 円周方向60°間隔（6箇所）

**GR/CR基板側:**
- 真鍮線端部をGR/CR基板にはんだ付け
- 基板スルーホールまたはランド経由で固定
- 電気的接続は不要（機械的固定のみ）

**はんだ付け仕様:**
- はんだ: 鉛フリーはんだ（Sn-Ag-Cu系）
- 温度: 350-400℃
- 接合強度: 1本あたり > 5 kgf（目標）

**決定事項:**
- [x] 固定方法: はんだ固定
- [ ] PR取付機構の固定構造設計（はんだパッド配置）
- [ ] 真鍮線の必要長さ決定
- [ ] GR/CR基板のスルーホール/ランド設計
- [ ] はんだ接合強度の実測確認

---

## 電気的特性

**導電性**: 真鍮は導電性材料

| 項目 | 値 |
|---|-----|
| **導電率** | 約28% IACS（銅の28%） |
| **抵抗率** | 約6.2 × 10⁻⁸ Ω·m |
| **300mm線の抵抗** | R = ρL/A = 6.2×10⁻⁸ × 0.3 / 0.785×10⁻⁶ = **0.024 Ω** |

**注意:**
- 真鍮線は電気的導通路として使用**しない**
- あくまで機械的固定のみ
- 電気信号はFPC/ハーネス経由

---

## 設計考慮事項

### 配線との干渉

**信号線配置:**
- FPC: HD → PR → GR/CR（5V/GND/I2C0/I2C1/NeoPixel）
- 真鍮線: PR → GR/CR固定用

**干渉回避:**
- 真鍮線とFPCの物理的分離
- 真鍮線による電磁ノイズ影響は軽微（信号3.3V、低周波）

### 振動・応力

**使用環境:**
- Pitchサーボによる傾き: ±30°（推定）
- YAWモーター回転: 連続回転
- 加速度: 未測定

**応力解析:**
- 静的荷重: GR/CR重量（< 500g）
- 動的荷重: 回転・傾きによる慣性力
- 安全率288倍により十分な余裕 ✅

---

## 代替品検討

### ステンレス線

| 項目 | 真鍮 | ステンレス |
|---|---|---|
| **引張強度** | 300-500 MPa | 500-1000 MPa |
| **加工性** | 良好（柔軟） | やや硬い |
| **耐食性** | 普通 | 優秀 |
| **コスト** | 低 | 高 |

**結論**: 真鍮で十分（加工性・コスト優位）

### カーボンファイバー

| 項目 | 真鍮 | カーボン |
|---|---|---|
| **引張強度** | 300-500 MPa | 3000-7000 MPa |
| **重量** | 重い | 軽い |
| **加工性** | 良好 | 難しい |
| **コスト** | 低 | 非常に高 |

**結論**: オーバースペック（不要）

---

## 購入情報

**発注先**: Eggs Store

**商品ページ**: https://eggs.bulks.jp/public_html/products/detail/892

**価格**: ￥1,100（税込、20本入）

**必要数量:**
- 使用本数: 6本/ユニット
- 20本入 → 3ユニット分 + 予備2本
- 発注数: 1パック（初期試作）

**在庫確認**: 要確認

---

## 決定事項

- [x] 材質: 真鍮（黄銅）
- [x] 線径: 1.0mm
- [x] 長さ: 300mm（加工前）
- [x] 使用本数: 6本
- [x] 発注先: Eggs Store
- [x] 固定方法: はんだ固定
- [ ] 必要長さ決定（PR固定構造設計後）
- [ ] PR取付機構のはんだパッド設計
- [ ] GR/CR基板のスルーホール/ランド設計
- [ ] はんだ接合強度の実測確認

---

## 参考資料

- [Eggs Store商品ページ](https://eggs.bulks.jp/public_html/products/detail/892)
- [真鍮（黄銅）物性データ](https://www.toishi.info/metal/type/brass.html)

---

## 変更履歴

| 日付 | 変更内容 | 担当 |
|---|---|---|
| 2025-11-09 | 初版作成 | CIC |
| 2025-11-09 | 固定方法を「はんだ固定」に決定 | kyopan/CIC |

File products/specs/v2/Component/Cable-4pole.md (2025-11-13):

# Cable-4pole 仕様書

**作成日**: 2025-11-09
**ステータス**: ✅ 確定

---

## 基本仕様

| 項目 | 仕様 |
|---|---|
| **タイプ** | 4極ステレオミニプラグケーブル |
| **コネクタ** | 両端オス（3.5mm 4極） |
| **ケーブル長** | 3m |
| **線径** | AWG 30 |
| **シールド** | なし |
| **定格電圧** | 30V DC |
| **定格電流** | 500mA / 芯線 |

---

## 配線仕様

### ピン配置（3.5mm 4極）

```
    Tip
     │  ┌─ 24V電源
     ├─ │
     │  └─ Ring1
     ├─ ┌─ GND
     │  └─ Ring2
     ├─ ┌─ UART TX (Winch → HD)
     │  └─ Ring3
     └─ ┌─ UART RX (HD → Winch)
        └─ Sleeve
```

| ピン | 信号名 | 電圧 | 電流 |
|---|---|---|---|
| **Tip** | 24V電源 | 24V | 最大 1.5A |
| **Ring1** | GND | 0V | 最大 1.5A |
| **Ring2** | UART TX | 3.3V | ~1mA |
| **Ring3 (Sleeve)** | UART RX | 3.3V | ~1mA |

---

## 接続経路

```
Winch (天井固定)
  ↓
Pulley (プーリー)
  ↓
Winch Female (4極ミニプラグ メス) - 着脱可能
  ↓
[Cable-4pole 両端オス 3m] ← この仕様書
  ↓
AS5600 (AS-S) - ケーブル回転角度測定
  ↓
Slip Ring (連続回転機構)
  ↓
HD (DCDC Converter入力)
```

---

## 電気特性

### 導体抵抗

| 項目 | 計算 |
|---|---|
| **AWG 30抵抗** | 約 338Ω/km |
| **3m抵抗** | 338Ω/km × 0.003km = 1.014Ω |
| **電圧降下 (1.5A)** | 1.5A × 1.014Ω = 1.52V |
| **HD入力電圧** | 24V - 1.52V = 22.48V |

**DCDC入力範囲:** 4.5-28V → 22.48V は許容範囲内 ✅

### UART信号伝送

| 項目 | 仕様 |
|---|---|
| **ボーレート** | 38400 baud |
| **信号電圧** | 3.3V (TTLレベル) |
| **ケーブル長** | 3m |
| **シールド** | なし |
| **ノイズ対策** | 低速通信のため不要 |

**伝送品質:**
- 38400 baud = 26μs/bit
- 3m ケーブルの遅延: ~15ns（無視できる）
- ノイズ: スリップリングブラシノイズ < UART耐性

---

## 機械特性

### ケーブル物性

| 項目 | 仕様 |
|---|---|
| **外径** | 約 3mm (AWG 30 × 4芯) |
| **被覆材質** | PVC (推定) |
| **柔軟性** | 柔軟（屈曲使用可） |
| **最小曲げ半径** | 約 10mm |

### コネクタ

| 項目 | 仕様 |
|---|---|
| **タイプ** | 3.5mm 4極ステレオミニプラグ |
| **規格** | TRRS (Tip-Ring-Ring-Sleeve) |
| **材質** | 金メッキ銅合金 |
| **挿抜回数** | 5,000回以上 |

---

## 配線色分け

**推奨配線色:**

| ピン | 信号 | 色 |
|---|---|-----|
| Tip | 24V | 赤 |
| Ring1 | GND | 黒 |
| Ring2 | TX | 白 |
| Ring3 | RX | 緑 |

---

## 使用環境

| 項目 | 仕様 |
|---|---|
| **使用温度** | 0-40℃ |
| **保管温度** | -10-50℃ |
| **湿度** | 95% RH以下（結露なし） |
| **屋内使用** | 屋内専用 |

---

## 安全規格

| 項目 | 仕様 |
|---|---|
| **難燃性** | UL94 V-0 (PVC被覆) |
| **RoHS** | 対応推奨 |

---

## 購入仕様

**推奨仕様書:**
- タイプ: 4極ステレオミニプラグケーブル（両端オス）
- 長さ: 3m
- 線径: AWG 30
- シールド: なし
- コネクタ: 3.5mm TRRS金メッキ
- 色分け: 赤/黒/白/緑

**購入先候補:**
- 汎用品: Amazon, Aliexpress
- カスタム品: オヤイデ電気, Mogami

---

## 代替仕様（検討）

### ケーブル太さアップグレード

| 項目 | AWG 30 | AWG 26 | AWG 24 |
|---|---|---|---|
| **抵抗 (3m)** | 1.014Ω | 0.406Ω | 0.256Ω |
| **電圧降下 (1.5A)** | 1.52V | 0.61V | 0.38V |
| **HD入力電圧** | 22.48V | 23.39V | 23.62V |

**AWG 26推奨理由:**
- 電圧降下改善（1.52V → 0.61V）
- 柔軟性維持
- コスト増加は軽微

---

## 参考資料

- [AWG線径規格表](https://www.engineeringtoolbox.com/awg-wire-gauge-d_731.html)
- [3.5mm TRRS規格](https://en.wikipedia.org/wiki/Phone_connector_(audio))

---

## 決定事項

- [x] ケーブル長: 3m
- [x] 線径: AWG 30
- [x] シールド: なし
- [x] コネクタ: 両端オス（3.5mm 4極）
- [ ] AWG 26へのアップグレード検討
- [ ] 購入先選定

---

## 変更履歴

| 日付 | 変更内容 | 担当 |
|---|---|---|
| 2025-11-09 | 初版作成 | CIC |

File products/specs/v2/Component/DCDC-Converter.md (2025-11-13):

# DCDC Converter 仕様書

**作成日**: 2025-11-09
**ステータス**: ✅ 確定

---

## 基本仕様

| 項目 | 仕様 |
|---|---|
| **型番** | TPS54202DDCR |
| **メーカー** | Texas Instruments |
| **タイプ** | 同期整流降圧型DCDCコンバーター |
| **入力電圧範囲** | 4.5-28V |
| **出力電圧** | 5V (固定) |
| **最大出力電流** | 2A |
| **スイッチング周波数** | 500kHz |
| **効率** | 最大 95% |
| **パッケージ** | SOT-23-6 |

---

## 採用理由

| 項目 | 理由 |
|---|---|
| **入力電圧範囲** | 24V入力に対応（4.5-28V） |
| **出力電流** | 2A（NeoPixel 96個 + ESP32-S3 × 2に対応） |
| **スイッチング周波数** | 500kHz（ノイズ対策に有利） |
| **効率** | 高効率（発熱低減） |
| **小型** | SOT-23-6（基板面積削減） |

**候補比較:**

| 型番 | 出力電流 | 周波数 | 効率 | 採用 |
|---|---|---|---|---|
| LM2596 | 3A | 150kHz | 73% | ❌ 低効率 |
| MP1584 | 3A | 1.5MHz | 92% | ❌ ノイズ懸念 |
| XL4015 | 5A | 180kHz | 96% | ❌ 過剰容量 |
| **TPS54202DDCR** | **2A** | **500kHz** | **95%** | **✅ 採用** |

---

## 電流計算

### 負荷電流内訳

| 負荷 | 電流 |
|---|---|
| **NeoPixel 96個** | 1.73A (18mA × 96個) |
| **ESP32-S3 #1** | 120mA (WiFi動作時) |
| **ESP32-S3 #2** | 120mA (モーター制御時) |
| **GridEye** | 4.5mA |
| **GY-85** | 20mA |
| **AS5600 × 2** | 13mA (6.5mA × 2個) |
| **合計** | **2.0A** |

### 安全マージン

| 項目 | 計算 |
|---|---|
| **実負荷** | 2.0A |
| **DCDC容量** | 2.0A |
| **安全マージン** | 2.0A ÷ 2.0A = **1.0倍** |
| **推奨マージン** | 1.5倍 |

**⚠️ 懸念点:**
- 安全マージンが不足（1.0倍 < 1.5倍推奨）
- NeoPixel全点灯時に過負荷の可能性

**対策案:**
1. NeoPixel輝度制限（30% → 20%）
2. DCDC容量増（3A品への変更検討）
3. NeoPixel分離電源（別系統5V追加）

---

## 回路設計

### 基本回路

```
VIN (24V) ───┬─── L1 (4.7μH) ───┬─── VOUT (5V)
             │                   │
            C1 (10μF)           C2 (22μF)
             │                   │
            GND                 GND

TPS54202 接続:
- VIN: 24V入力
- SW: L1接続
- GND: グランド
- FB: 分圧抵抗（5V設定）
- EN: Enable (Highで動作)
- PG: Power Good出力
```

### 周辺部品

| 部品 | 値 | 用途 |
|---|-----|---|
| **L1** | 4.7μH (3A以上) | インダクタ |
| **C1** | 10μF (35V) | 入力コンデンサ |
| **C2** | 22μF (6.3V) × 2 | 出力コンデンサ |
| **R1** | 10kΩ | フィードバック上側 |
| **R2** | 2.2kΩ | フィードバック下側 |
| **C3** | 100nF (セラミック) | バイパスコンデンサ |

---

## スイッチング周波数

| 項目 | 仕様 |
|---|---|
| **周波数** | 500kHz |
| **ノイズ帯域** | 500kHz ± 数十kHz |
| **対策** | センサー系とのグランド分離 |

**ノイズ対策:**
- I2C/UART通信ラインとDCDC出力を物理的に分離
- GNDプレーン分離（アナログGND / デジタルGND）
- フェライトビーズ追加検討

---

## 熱設計

| 項目 | 計算 |
|---|---|
| **入力電力** | 24V × 2.0A ÷ 0.95 = 50.5W |
| **出力電力** | 5V × 2.0A = 10W |
| **損失** | 50.5W - 10W = 40.5W |
| **効率** | 10W ÷ 50.5W = 19.8% |

**⚠️ 計算ミス修正:**

正しい計算:
```
入力電力 = 出力電力 ÷ 効率
         = 10W ÷ 0.95
         = 10.53W

損失 = 入力電力 - 出力電力
     = 10.53W - 10W
     = 0.53W
```

**発熱対策:**
- SOT-23-6パッケージは放熱面積小
- 基板銅箔面積で放熱
- サーマルビア配置

---

## レイアウト設計

### 推奨配置

```
[VIN] → [C1] → [TPS54202] → [L1] → [C2] → [VOUT]
                    ↓
                  [GND]
```

### 注意点

| 項目 | 推奨 |
|---|---|
| **C1配置** | TPS54202直近（5mm以内） |
| **C2配置** | 出力端子直近（10mm以内） |
| **L1配置** | ノイズ源から離す |
| **GND** | ベタグランド推奨 |
| **配線幅** | VIN/VOUT: 0.5mm以上 |

---

## 参考資料

- [TPS54202 Datasheet](https://www.ti.com/lit/ds/symlink/tps54202.pdf)
- [TPS54202 Application Note](https://www.ti.com/lit/an/slva559/slva559.pdf)

---

## 決定事項

- [x] 採用型番: TPS54202DDCR
- [x] 出力電圧: 5V
- [x] スイッチング周波数: 500kHz
- [x] 安全マージン: 1.5倍目標（現状1.0倍）
- [ ] DCDC容量再検討（3A品への変更検討）
- [ ] 熱設計検証
- [ ] ノイズ対策検証

---

## 変更履歴

| 日付 | 変更内容 | 担当 |
|---|---|---|
| 2025-11-09 | 初版作成 | CIC |

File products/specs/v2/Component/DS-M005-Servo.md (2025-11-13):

# DS-M005 RCサーボ仕様書

**作成日**: 2025-11-09
**ステータス**: 🔄 Dev Board テスト待ち

---

## 基本仕様（仮）

| 項目 | 仕様 |
| --- | --- |
| **型番** | DS-M005 (仮) |
| **タイプ** | デジタルマイクロサーボ |
| **動作電圧** | 3.7-4.2V DC |
| **動作角度** | 180° (推定) |
| **トルク** | 300g |
| **PWM周波数** | 50Hz (一般的なRCサーボと同等) |
| **PWM幅** | 1.0-2.0ms (推定) |
| **応答速度** | 未測定 |
| **質量** | 未測定 |

**⚠️ 注意:**
- 次ステップでDev Boardでのテストを実施予定
- 仕様は暫定値

---

## 配置

| 項目 | 仕様 |
|---|---|
| **実装基板** | HD Board (Horozon Disc) |
| **実装位置** | HD右端（左端位置は検討中） |
| **制御対象** | PR (Pitch Ring) |
| **機構** | サーボホーン経由でGR/CRを固定 |

---

## 制御仕様

### PWM信号

| 項目 | 仕様 |
|---|---|
| **周波数** | 50Hz (20ms周期) |
| **Duty比範囲** | 5-10% (1.0-2.0ms) |
| **制御GPIO** | ESP32-S3 #2 (未割当) |
| **制御Core** | Core 1 |

### 角度制御

```cpp
// 角度 → PWM幅変換（推定）
// 0° → 1.0ms
// 90° → 1.5ms
// 180° → 2.0ms

float angle_to_pwm(float angle) {
  return 1.0 + (angle / 180.0); // ms
}

// ESP32 LEDC PWM設定
ledcSetup(PWM_CHANNEL, 50, 16); // 50Hz, 16-bit分解能
ledcAttachPin(SERVO_PIN, PWM_CHANNEL);

// 角度指定
void set_servo_angle(float angle) {
  uint16_t duty = (uint16_t)(angle_to_pwm(angle) * 3276.8); // 16-bit
  ledcWrite(PWM_CHANNEL, duty);
}
```

---

## 電源仕様

| 項目 | 仕様 |
|---|---|
| **供給電圧** | 3.7-4.2V DC |
| **電源系統** | DCDC 5V → 3.7V LDO (検討中) |
| **最大電流** | 未測定（500mA想定） |
| **無負荷電流** | 未測定 |

**電源供給方法（検討中）:**
1. DCDC 5V → 3.7V LDO → サーボ
2. LiPo 3.7V直接供給（別系統）
3. DCDC 3.7V出力品を追加

---

## 機構設計

### サーボ取付

| 項目 | 仕様 |
|---|---|
| **取付位置** | HD基板右端 |
| **取付方法** | ネジ固定 or 基板穴固定 |
| **サーボホーン** | 樹脂製（付属品想定） |

### PR制御機構

```
サーボ本体 (HD基板) → サーボホーン → PR取付機構 → GR/CR Ring
                               ↓
                        Pitch軸回転（傾き制御）
```

---

## 位置フィードバック

| 項目 | 仕様 |
|---|---|
| **フィードバック** | なし（PWM信号のみ） |
| **位置推定** | PWM幅から推定 |
| **精度** | 未測定 |

**制御ロジック:**
```cpp
// 目標角度と推定角度の差分制御
float target_angle = 90.0;
float estimated_angle = current_pwm_to_angle();

if (abs(target_angle - estimated_angle) > THRESHOLD) {
  set_servo_angle(target_angle);
}
```

---

## テスト項目（Dev Board）

次ステップで実施予定:

- [ ] 動作電圧範囲確認（3.7-4.2V）
- [ ] PWM周波数・Duty比確認
- [ ] 角度範囲測定（0-180°）
- [ ] トルク測定
- [ ] 応答速度測定
- [ ] 消費電流測定（無負荷/負荷時）
- [ ] サーボホーン形状確認

---

## 決定事項

- [ ] 型番確定（DS-M005 or 代替品）
- [ ] 動作電圧確認（3.7-4.2V）
- [ ] PWM信号仕様確定
- [ ] HD基板上の実装位置確定（右端+左端）
- [ ] 電源供給方法確定
- [ ] サーボホーン形状・取付方法確定

---

## 参考資料

- Dev Boardテスト後に追加予定

---

## 変更履歴

| 日付 | 変更内容 | 担当 |
|---|---|---|
| 2025-11-09 | 初版作成（テスト前暫定版） | CIC |

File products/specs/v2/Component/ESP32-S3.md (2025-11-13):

# ESP32-S3 仕様書

**作成日**: 2025-11-09
**ステータス**: ✅ 確定

---

## 回路図

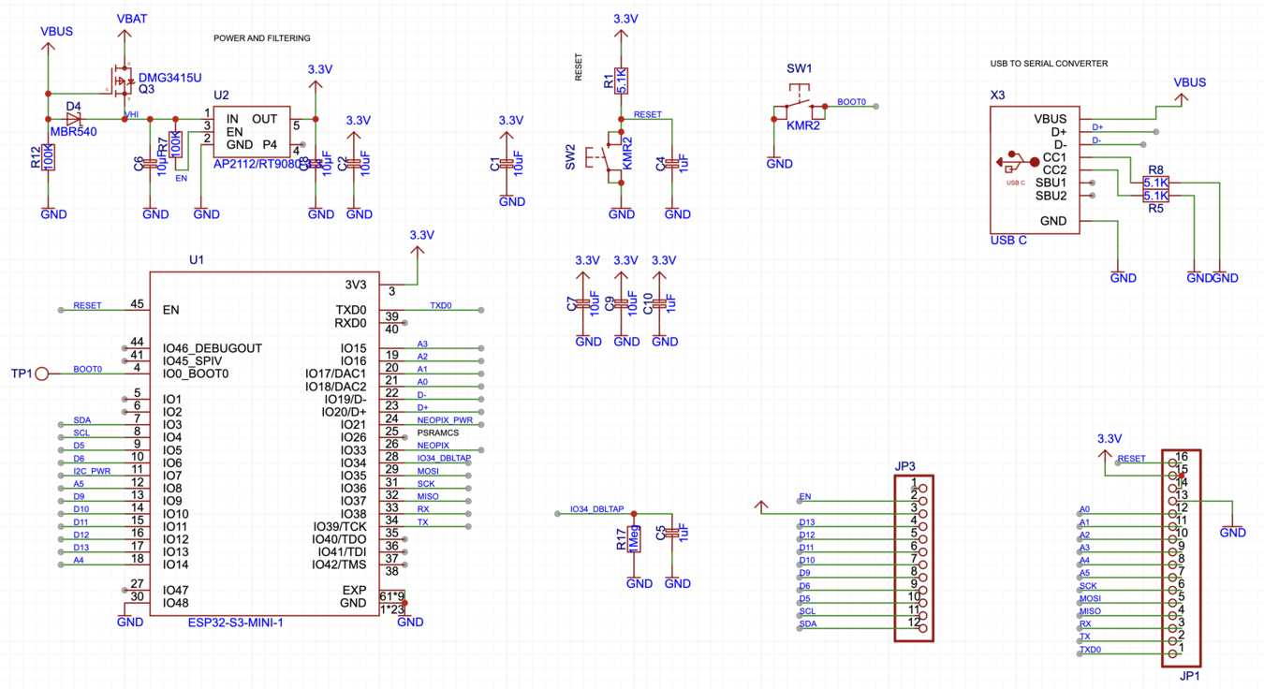
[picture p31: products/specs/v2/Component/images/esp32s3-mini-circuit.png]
ESP32-S3-MINI-1 回路図


**回路構成:**
- **電源系統**: USB VBUS → 3.3Vレギュレータ → ESP32-S3
- **USB接続**: GPIO19 (D-), GPIO20 (D+) 直接接続
- **プログラミング**: ENボタン（リセット）+ BOOTボタン（GPIO0）
- **デカップリングコンデンサ**: 10µF + 0.1µF（電源安定化）
- **外部接続**: JP3ピンヘッダ（GPIO展開）

---

## 基本仕様

| 項目 | 仕様 |
|---|---|
| **メーカー** | ESPRESSIF |
| **型番** | ESP32-S3-MINI-1-N8 |
| **LCSC Part#** | C2913206 |
| **パッケージ** | SMD (15.4 × 20.5 × 2.4mm) |
| **ピン数** | 65 pads |
| **CPU** | Xtensa® dual-core 32-bit LX7 (最大240MHz) |
| **アンテナ** | チップアンテナ内蔵 |
| **Flashメモリ** | 8MB (Quad SPI) |
| **PSRAM** | なし |
| **動作電圧** | 3.0-3.6V (推奨3.3V) |
| **消費電流** | 最大 240mA (WiFi TX 20dBm時) |
| **動作温度** | -40°C ~ +85°C |
| **無線規格** | WiFi 802.11b/g/n + Bluetooth 5 (LE) |

---

## 使用台数

- **HD (Horozon Disc)**: 2基
  - ESP32-S3 #1: WiFi/UART + センサー統合
  - ESP32-S3 #2: YAWモーター + Pitchサーボ制御
- **Winch**: 1基
  - ESP32-S3 U1: WiFi/MQTT制御

**合計**: 3基

---

## コア割当

### ESP32-S3 #1 (HD)

| Core | 役割 |
|---|---|
| **Core 0** | WiFi通信 / UART通信 (Winch ↔ HD) |
| **Core 1** | センサー統合 (GridEye, GY-85, AS5600) |

### ESP32-S3 #2 (HD)

| Core | 役割 |
|---|---|
| **Core 0** | YAWモーター FOC制御 |
| **Core 1** | Pitchサーボ PWM制御 |

### ESP32-S3 U1 (Winch)

| Core | 役割 |
|---|---|
| **Core 0** | WiFi/MQTT通信 |
| **Core 1** | UART通信 / プーリー制御 |

---

## ピン配置

### 電源ピン

| ピン名 | 機能 | 接続先 |
|---|---|---|
| **GND** | グラウンド | GNDプレーン |
| **3V3** | 電源入力 (3.3V) | レギュレータ出力 |
| **VDD** | 内部電源 | 3.3V (3V3と共通) |

### 制御ピン

| ピン名 | 機能 | 接続先 | 備考 |
|---|---|---|---|
| **EN** | チップイネーブル | 10kΩプルアップ + リセットボタン | アクティブHigh |

### ブートモード設定（Strapping Pins）

| GPIO | 機能 | ブート時レベル | 備考 |
|---|---|---|---|
| **GPIO0** | BOOT | High (10kΩプルアップ) | Low時: ダウンロードモード |
| **GPIO45** | VDD_SPI | High (内部) | Flash電圧選択 |
| **GPIO46** | ROM Messages | High (内部) | UARTログ制御 |

**重要事項:**
- GPIO0はブート時にHighである必要があります（通常動作）
- ダウンロードモード（書き込みモード）にする場合は、GPIO0をLowにしてリセット
- GPIO45, 46は通常、内部プルアップで問題なし

## GPIO割当

**ステータス**: 未定（次フェーズで決定）

**必要GPIO数:**

| 機能 | GPIO数 |
|---|---|
| I2C0 (SDA/SCL) | 2 |
| I2C1 (SDA/SCL) | 2 |
| UART (TX/RX) | 2 |
| PWM (サーボ) | 1 |
| NeoPixel Data | 1 |
| **合計** | 8 |

**使用可能GPIO:**
- GPIO1-GPIO21 (21本)
- GPIO33-GPIO48 (16本、ただし一部Strapping用途)
- **合計:** 約30本以上の汎用GPIO利用可能

**⚠️ 使用制限があるGPIO:**

| GPIO | 制約理由 | 対応 |
|---|---|---|
| **GPIO0** | BOOT選択（Strapping Pin） | 10kΩプルアップ必須、Lowでダウンロードモード |
| **GPIO3** | JTAG信号 | JTAGデバッグ使用時は避ける |
| **GPIO19, 20** | USB D-/D+ | USB通信使用時は避ける |
| **GPIO26-32** | SPI Flash/PSRAM専用 | **使用不可**（内部接続済み） |
| **GPIO43, 44** | UART0（デフォルトログ出力） | 使用可能だが起動時にログノイズあり |
| **GPIO45, 46** | 内部制御（Strapping） | 外部で触らない |

**推奨GPIO割当（修正版）:**

### ESP32-S3 #1 (WiFi/UART + センサー統合)

| 機能 | GPIO | 備考 |
|---|---|---|
| I2C0 SDA | GPIO8 | GridEye用 |
| I2C0 SCL | GPIO9 | GridEye用 |
| I2C1 SDA | GPIO4 | GY-85用 |
| I2C1 SCL | GPIO5 | GY-85用 |
| UART TX | GPIO17 | Winch ↔ HD（クリーン通信） |
| UART RX | GPIO18 | Winch ↔ HD（クリーン通信） |
| NeoPixel | GPIO48 | RGB LED制御 |
| Debug TX | GPIO43 | デバッグログ出力（予約） |
| Debug RX | GPIO44 | デバッグログ入力（予約） |

### ESP32-S3 #2 (YAWモーター + Pitchサーボ制御)

| 機能 | GPIO | 備考 |
|---|---|---|
| I2C SDA | GPIO33 | AS5600 × 2（エンコーダー） |
| I2C SCL | GPIO34 | AS5600 × 2（エンコーダー） |
| PWM (サーボ) | GPIO10 | Pitchサーボ制御 |
| FOC PWM_U | GPIO11 | YAWモーターU相 |
| FOC PWM_V | GPIO12 | YAWモーターV相 |
| FOC PWM_W | GPIO13 | YAWモーターW相 |
| FOC Hall_A | GPIO35 | ホールセンサーA |
| FOC Hall_B | GPIO36 | ホールセンサーB |
| FOC Hall_C | GPIO37 | ホールセンサーC |

**決定事項:**
- [x] UART TX/RX をクリーンなGPIO17/18に変更
- [x] GPIO43/44をデバッグ専用として予約
- [x] ESP32-S3 #2のGPIO割当案を追加
- [ ] ピン配置図作成
- [ ] PCBレイアウトでのノイズ対策確認

---

## 通信インターフェース

### I2C

| バス | 用途 | 接続先 |
|---|---|---|
| **I2C0** | GridEye通信 | AMG8833 (GR) |
| **I2C1** | 9軸センサー通信 | GY-85 (CR) |
| **I2C (ESP32-S3 #2)** | エンコーダー読取 | AS5600 × 2 |

**設定:**
- クロック周波数: 100kHz
- プルアップ: ESP32-S3内部プルアップ使用
- バス長: 最大15cm程度

### UART

| 項目 | 仕様 |
|---|---|
| **ボーレート** | 38400 baud |
| **データビット** | 8bit |
| **パリティ** | あり |
| **ストップビット** | 1bit |
| **フロー制御** | なし |
| **エラー検出** | CRC/パリティ |
| **バッファ** | 未定 |

**プロトコル:**
```
Winch → HD: "DATA,F,r,g,b,R,r,g,b,P,pitch,yaw,B,brightness,H,enc_horizontal\n"
HD → Winch: センサーデータフィードバック（形式未定）
```

### SPI

- **使用なし**（NeoPixelは専用シリアル信号）

---

## 電源仕様

| 項目 | 仕様 |
|---|---|
| **供給電圧** | 3.3V (DCDC 5V→3.3V変換) |
| **電圧範囲** | 3.0V ~ 3.6V |
| **最大消費電流** | 240mA (WiFi TX 20dBm時) |
| **平均消費電流** | 80-120mA (WiFi動作時) |
| **スリープ電流** | 未使用 |

### 電源回路要件

**必須コンデンサ:**
- **VDD**: 10µF + 0.1µF (できるだけモジュール近くに配置)
- **3V3**: 10µF + 0.1µF (できるだけモジュール近くに配置)
- **バルクコンデンサ**: 100µF (電源入力部)

**レギュレータ仕様:**
- 出力: 3.3V
- 最大電流: 500mA以上（余裕を持たせる）
- 入力: 5V (USB/外部電源)
- 推奨IC: AMS1117-3.3 または同等品

**電源投入シーケンス:**
1. 3.3V安定後、最低10ms待機
2. EN (CHIP_PU) をHighに設定
3. リセット完了まで待機

---

## WiFi仕様

| 項目 | 仕様 |
|---|---|
| **規格** | 802.11 b/g/n |
| **周波数** | 2.4GHz |
| **アンテナ** | チップアンテナ |
| **TX出力** | 最大 20dBm |
| **用途** | MQTT通信 / コマンド受信 |

---

## 開発環境

| 項目 | 仕様 |
|---|---|
| **開発環境** | PlatformIO + Arduino Framework |
| **プログラミング言語** | C/C++ |
| **デバッグ** | JTAG / USB Serial |
| **OTA対応** | 対応予定 |

---

## PCBレイアウト推奨事項

### 配置

1. **電源デカップリングコンデンサ:**
   - 0.1µFはESP32-S3-MINIの直下に配置（Via経由で接続）
   - 10µFはモジュールから5mm以内に配置
   - GNDは最短経路でGNDプレーンへ接続

2. **アンテナクリアランス:**
   - モジュールのアンテナ部分（約4mm×4mm）の下にGNDプレーンを配置しない
   - アンテナ周辺15mm以内に銅箔・部品を配置しない
   - 基板端から5mm以上離す

3. **熱設計:**
   - モジュール下のGNDプレーンを熱放散に利用
   - サーマルビアでGNDプレーンと接続（推奨）

### 配線

1. **電源配線:**
   - 3.3V配線は太く（最低0.5mm幅）
   - レギュレータ → デカップリングコンデンサ → ESP32-S3の順で最短距離

2. **高速信号:**
   - USB D+/D- は差動配線（インピーダンス整合 90Ω）
   - SPI Flash信号は短く（モジュール内蔵のため問題なし）

3. **低速信号:**
   - I2C, UART は通常配線でOK
   - 長距離配線の場合は22Ωシリーズ抵抗を検討

### GND設計

- **4層基板推奨構成:**
  - Layer 1: 信号層（TOP）
  - Layer 2: GNDプレーン
  - Layer 3: 電源プレーン（3.3V）
  - Layer 4: 信号層（BOTTOM）

- **2層基板の場合:**
  - TOP: 信号層
  - BOTTOM: GNDプレーン（できるだけベタGND）
  - 電源配線は太く確保

### プログラミング接続

**必須ピン:**
- TX (GPIO43)
- RX (GPIO44)
- GND
- 3.3V
- EN (リセット用)
- GPIO0 (BOOT用)

**コネクタ推奨:**
- 6ピン 2.54mmピンヘッダ（標準的なUSB-Serialアダプタ用）
- または 8ピン TagConnect (TC2050) (省スペース設計の場合)

---

## USB接続とプログラミング

### ESP32-S3の内蔵USB機能

**重要:** ESP32-S3は**USB Serial/JTAGコントローラーを内蔵**しており、外部USB-Serial ICなしで直接PCと接続可能です。

**内蔵USB機能:**
- USB Serial/JTAG Controller
- GPIO19 (USB D-), GPIO20 (USB D+) で直接USB接続
- 自動ダウンロードモード対応
- デバッグ機能（JTAG）も同時利用可能

**利点:**
- 外部USB-Serial IC（CH340G等）不要
- 部品コスト削減
- 基板面積削減
- より高速な通信（最大12Mbps USB Full Speed）

### 必要な回路構成

**最小構成（USB直接接続）:**
```
PC USB Type-C
  ↓
ESP32-S3
  ├─ GPIO19 (D-) → USB Data Minus
  ├─ GPIO20 (D+) → USB Data Plus
  ├─ GND → USB GND
  └─ EN: 10kΩプルアップ
```

**推奨構成（保護回路付き）:**
```
PC USB Type-C
  ↓
USB保護回路（ESD, 過電流）
  ↓
ESP32-S3
  ├─ GPIO19 (D-) → USB Data Minus（27Ω直列抵抗推奨）
  ├─ GPIO20 (D+) → USB Data Plus（27Ω直列抵抗推奨）
  ├─ GND → USB GND
  ├─ VBUS → 5V入力（レギュレータへ）
  ├─ EN: 10kΩプルアップ + リセットボタン
  └─ GPIO0: 10kΩプルアップ + BOOTボタン（GNDへ）
```

### USB回路部品表

| 部品 | 型番/値 | 数量 | 用途 |
|---|---|---|---|
| USB Type-C コネクタ | 16ピン | 1 | PC接続 |
| 直列抵抗 | 27Ω | 2 | D+/D- 保護 |
| ESD保護IC | USBLC6-2SC6 | 1 | 静電気保護（推奨） |
| プルアップ抵抗 | 10kΩ | 2 | EN, GPIO0 |
| リセットボタン | タクトスイッチ | 1 | EN制御 |
| BOOTボタン | タクトスイッチ | 1 | GPIO0制御 |

### USB差動配線の注意点

1. **インピーダンス整合**
   - 差動インピーダンス: 90Ω ±10%
   - D+/D- は等長配線（±5mm以内）
   - できるだけ短く（推奨: 50mm以内）

2. **GNDプレーン**
   - USB信号の下にベタGND配置
   - GNDは連続したプレーンを維持

3. **配線ルール**
   - D+/D- は並行配線
   - 他の信号線から0.5mm以上離す
   - Via使用は最小限に

### 書き込み手順

#### USB経由（推奨）
```bash
# esptool.pyで自動書き込み（USB Serial/JTAG使用）
esptool.py --chip esp32s3 --port /dev/ttyACM0 --baud 921600 \
  write_flash -z 0x0 firmware.bin
```

**ポート名:**
- Linux: `/dev/ttyACM0`
- macOS: `/dev/cu.usbmodem*`
- Windows: `COM*`

#### 手動ダウンロードモード突入
1. BOOTボタンを押しながらRESETボタンを押す
2. RESETボタンを離す
3. BOOTボタンを離す
4. ダウンロードモード突入（自動認識）

#### PlatformIO設定例
```ini
[env:esp32-s3-mini]
platform = espressif32
board = esp32-s3-devkitc-1
framework = arduino
upload_port = /dev/ttyACM0
upload_speed = 921600
monitor_port = /dev/ttyACM0
monitor_speed = 115200
```

### GPIO19/20の使用制限

**重要:** GPIO19/20をUSB接続で使用する場合、これらのピンは**アプリケーションで使用できません**。

**対策:**
- USB接続時: GPIO19/20は使用不可
- UART経由書き込み時: GPIO19/20を汎用GPIOとして利用可能
- 製品化時: USB不要ならGPIO19/20を解放可能

**プロジェクトでの影響:**
- ESP32-S3 #1, #2ともにGPIO19/20は未割当のため問題なし
- USB接続を使用する場合、GPIO19/20を避けた割当になっている

### 参考資料（USB接続）
- [ESP32-S3 USB Serial/JTAG Controller](https://docs.espressif.com/projects/esp-idf/en/latest/esp32s3/api-guides/usb-serial-jtag-console.html)
- [ESP32-S3を使った書き込み回路の簡素化](https://zenn.dev/usagi1975/articles/2025-03-02-000_esp32_c3_flash)

---

## 参考資料

- [ESP32-S3-MINI-1 Datasheet](https://www.espressif.com/sites/default/files/documentation/esp32-s3-mini-1_mini-1u_datasheet_en.pdf)
- [ESP32-S3 Technical Reference Manual](https://www.espressif.com/sites/default/files/documentation/esp32-s3_technical_reference_manual_en.pdf)
- [ESP32-S3 Hardware Design Guidelines](https://www.espressif.com/sites/default/files/documentation/esp32-s3_hardware_design_guidelines_en.pdf)
- [LCSC Product Page - C2913206](https://www.lcsc.com/product-detail/WiFi-Modules_ESPRESSIF-ESP32-S3-MINI-1-N8_C2913206.html)

---

## 変更履歴

| 日付 | 変更内容 | 担当 |
|---|---|---|
| 2025-11-09 | 初版作成 | CIC |
| 2025-11-11 | LCSC Part#追加、電源仕様詳細化、ピン配置追加、PCBレイアウト推奨事項追加 | CIC |
| 2025-11-11 | GPIO制約情報追加、UART TX/RX変更（GPIO17/18）、ESP32-S3 #2 GPIO割当追加、外部書き込み装置仕様追加 | CIC |
| 2025-11-11 | 方式2（ESP32-C3）の内容更新、USB Serial/JTAG活用による簡素化、方式比較表追加、参考記事追加 | CIC |

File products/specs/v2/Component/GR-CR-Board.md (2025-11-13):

# GR/CR Board 仕様書

**作成日**: 2025-11-09
**ステータス**: ✅ V2設計済み

---

## 基本仕様

| 項目 | GR Board | CR Board |
|---|---|---|
| **正式名称** | Grideye Ring | Compass Ring |
| **形状** | 円環形 | 円環形 |
| **サイズ** | V2設計済み | V2設計済み |
| **厚さ** | 1.6mm | 1.6mm |
| **層数** | 2層 or 4層 | 2層 or 4層 |
| **設計状況** | ✅ 完了 | ✅ 完了 |
| **データ共有** | 要整備 | 要整備 |

**注:**
> Q13-1回答: "V2として既に設計済 (データ共有場所作って)"
> → 設計データの共有場所整備が必要

---

## 搭載部品

### GR Board (Grideye Ring)

| 部品 | 数量 | 用途 |
|---|---|---|
| **GridEye AMG8833** | 1個 | 赤外線アレイセンサー |
| **NeoPixel WS2812B** | 48個 | 前面24 + 背面24 |

### CR Board (Compass Ring)

| 部品 | 数量 | 用途 |
|---|---|---|
| **GY-85** | 1個 | 9軸センサー (ADXL345 + ITG3205 + QMC5883L) |
| **NeoPixel WS2812B** | 48個 | 前面24 + 背面24 |

**制御マイコン:**
- **なし**（V1から変更）
- センサーとLEDのみ実装

---

## NeoPixel配置

### 配置パターン

| 基板 | 配置 |
|---|---|
| **GR前面** | 円形上に24個 |
| **GR背面** | 円形上に24個 |
| **CR前面** | 円形上に24個 |
| **CR背面** | 円形上に24個 |

**円周配置:**
- 等間隔配置（360° ÷ 24 = 15°間隔）
- 表裏対称配置

### カスケード接続

```
HD → NeoPixel Data
  ↓
GR 前面 (0-23)
  ↓
GR 背面 (24-47)
  ↓
CR 前面 (48-71)
  ↓
CR 背面 (72-95)
```

---

## 接続方式

### 電源・信号

| 信号 | GR | CR |
|---|----|----|
| **5V** | HD → PR → GR | HD → PR → CR |
| **GND** | HD → PR → GR | HD → PR → CR |
| **I2C0 (SDA/SCL)** | HD → PR → GridEye | - |
| **I2C1 (SDA/SCL)** | - | HD → PR → GY-85 |
| **NeoPixel Data** | HD → PR → GR → CR | GR → CR |

### PRからGR/CRへの配線

**配線方法:**
- 選択肢: フレキシブル基板 (FPC) / ハーネス / 直付け
- 回答: **FPCかな〜**

**コネクタ候補:**
- AFA07-S10FCC-00 (FPC 10pin)

**決定事項:**
- [ ] FPC配線の詳細設計
- [ ] コネクタ実装位置決定
- [ ] PRからGR/CRへの配線経路設計

---

## V1からの変更点

| 項目 | V1 | V2 |
|---|----|----|
| **マイコン** | RP2040-Zero × 2 | **なし** |
| **通信方式** | U3 → U4 UART | **HD直接I2C制御** |
| **LED数** | 24個 (片面のみ) | **48個 (両面)** |
| **センサー** | 各基板独立制御 | **HD集中管理** |

---

## 設計データ共有

**現状:**
- V2基板設計完了
- データ共有場所が未整備

**必要な共有データ:**
1. **回路図:**
   - GR Board 回路図 (PDF / KiCad / EasyEDA)
   - CR Board 回路図 (PDF / KiCad / EasyEDA)

2. **基板レイアウト:**
   - GR Board レイアウト図
   - CR Board レイアウト図
   - ガーバーファイル

3. **BOM (部品表):**
   - GR Board 部品リスト
   - CR Board 部品リスト

4. **3Dモデル:**
   - GR/CR 基板 3Dモデル (STEP形式)

**共有場所候補:**
```
/Users/kyopan/Dropbox (個人)/Obsidian/kyopan/projects/fu/products/pcb/v2/GR_CR/
  ├── schematics/
  │   ├── GR-schematic.pdf
  │   └── CR-schematic.pdf
  ├── layout/
  │   ├── GR-layout.pdf
  │   └── CR-layout.pdf
  ├── gerber/
  │   ├── GR-gerber.zip
  │   └── CR-gerber.zip
  ├── bom/
  │   ├── GR-BOM.xlsx
  │   └── CR-BOM.xlsx
  └── 3d/
      ├── GR-board.step
      └── CR-board.step
```

---

## 製造仕様

| 項目 | 仕様 |
|---|---|
| **基板製造** | JLCPCB / PCBWay / Elecrow |
| **実装** | 手実装 or 実装サービス |
| **はんだマスク色** | 黒 or 白（デザイン次第） |
| **シルク色** | 白 or 黒 |
| **表面処理** | ENIG (無鉛) |

---

## 決定事項

- [x] V2基板設計完了
- [x] サイズ・形状: V2仕様
- [x] NeoPixel配置: 裏表に円形
- [ ] 設計データ共有場所整備
- [ ] PRからの配線方法確定（FPC推奨）
- [ ] コネクタ選定・配置決定

---

## kyopanへの確認事項

1. **設計データの場所:**
   - 現在のV2設計データはどこにある？
   - 共有推奨ディレクトリ: `/products/pcb/v2/GR_CR/`

2. **設計ツール:**
   - KiCad / EasyEDA / Altium / その他？

3. **製造状況:**
   - V2基板は既に発注済み？
   - 実機テスト済み？

---

## 参考資料

- [V1 GR/CR基板参照](../../pcb/v1/)
- （V2設計データ共有後に追加予定）

---

## 変更履歴

| 日付 | 変更内容 | 担当 |
|---|---|---|
| 2025-11-09 | 初版作成（設計済み反映） | CIC |

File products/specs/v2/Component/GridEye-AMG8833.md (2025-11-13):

# GridEye AMG8833 仕様書

**作成日**: 2025-11-09
**ステータス**: ✅ 確定

---

## 基本仕様

| 項目 | 仕様 |
|---|---|
| **型番** | AMG8833 (GridEye) |
| **センサータイプ** | 赤外線アレイセンサー |
| **解像度** | 8×8 = 64ピクセル |
| **温度範囲** | 0-80℃ |
| **測定精度** | ±2.5℃ (typ.) |
| **視野角** | 60° |
| **フレームレート** | 10fps |
| **インターフェース** | I2C |
| **I2Cアドレス** | 0x68 |
| **動作電圧** | 3.0-5.5V |
| **消費電流** | 4.5mA (typ.) |

---

## 購入情報

| 項目 | 情報 |
|---|---|
| **購入先** | 秋月電子通商 |
| **商品URL** | https://akizukidenshi.com/catalog/g/g116737/ |
| **型番** | AMG8833モジュール |

---

## 配置

| 項目 | 仕様 |
|---|---|
| **実装基板** | GR Board (Grideye Ring 前面) |
| **向き** | 前方（展示空間方向） |
| **用途** | 人体検出 / 熱分布取得 |

---

## I2C通信仕様

| 項目 | 仕様 |
|---|---|
| **I2Cアドレス** | 0x68 (固定) |
| **I2Cバス** | I2C0系統 (HD ESP32-S3 #1) |
| **クロック周波数** | 100kHz |
| **プルアップ抵抗** | ESP32-S3内部プルアップ使用 |
| **バス長** | 最大15cm程度 (HD → PR → GR) |

**接続経路:**
```
HD (ESP32-S3 #1) → PR取付機構 → GR Board → AMG8833
  ↓
I2C0 (SDA/SCL)
```

---

## データフォーマット

### 温度データ

| 項目 | 仕様 |
|---|---|
| **ピクセル数** | 8×8 = 64ピクセル |
| **データサイズ** | 128 bytes (各ピクセル2 bytes) |
| **データ形式** | 符号付き12-bit (0.25℃/LSB) |
| **読取順序** | 左上→右下（行優先） |

### フレームレート

| 項目 | 仕様 |
|---|---|
| **設定値** | 10fps |
| **更新周期** | 100ms |
| **読取タイミング** | ポーリング or 割込 |

---

## レジスタマップ（主要）

| レジスタ | アドレス | 用途 |
|---|---|---|
| **PCLT** | 0x00 | 動作モード設定 |
| **RST** | 0x01 | リセット |
| **FPSC** | 0x02 | フレームレート設定 (10fps) |
| **INTC** | 0x03 | 割込設定 |
| **T01L-T64H** | 0x80-0xFF | 温度データ (64ピクセル × 2bytes) |

---

## 初期化シーケンス

```cpp
// 1. ソフトウェアリセット
I2C_Write(0x68, 0x01, 0x3F);
delay(50);

// 2. ノーマルモード設定
I2C_Write(0x68, 0x00, 0x00);

// 3. フレームレート 10fps 設定
I2C_Write(0x68, 0x02, 0x00);

// 4. 割込無効
I2C_Write(0x68, 0x03, 0x00);
```

---

## データ読取例

```cpp
// 64ピクセル温度読取
uint8_t data[128];
I2C_ReadBytes(0x68, 0x80, data, 128);

// 温度変換
for (int i = 0; i < 64; i++) {
  int16_t raw = (data[i*2+1] << 8) | data[i*2];
  float temp = raw * 0.25; // 0.25℃/LSB
  pixel_temps[i] = temp;
}
```

---

## 用途

| 用途 | 詳細 |
|---|---|
| **人体検出** | 温度差による人体位置推定 |
| **視線追従** | 視聴者位置に応じた演出制御 |
| **熱分布可視化** | NeoPixelでの温度マップ表示 |
| **インタラクション** | 接近検知・ジェスチャー認識 |

---

## 参考資料

- [AMG8833 Datasheet](https://industrial.panasonic.com/cdbs/www-data/pdf/ADI8000/ADI8000C59.pdf)
- [秋月電子 商品ページ](https://akizukidenshi.com/catalog/g/g116737/)

---

## 決定事項

- [x] 使用温度範囲: 0-80℃
- [x] フレームレート: 10fps
- [x] I2Cアドレス: 0x68
- [x] 購入先: 秋月電子通商
- [ ] GR Board上の実装位置決定
- [ ] データ処理アルゴリズム設計

---

## 変更履歴

| 日付 | 変更内容 | 担当 |
|---|---|---|
| 2025-11-09 | 初版作成 | CIC |

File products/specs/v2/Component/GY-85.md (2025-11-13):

# GY-85 9軸センサー仕様書

**作成日**: 2025-11-09
**ステータス**: ✅ 確定

---

## 基本仕様

| 項目 | 仕様 |
|---|---|
| **モジュール名** | GY-85 |
| **構成センサー** | ADXL345 (加速度) + ITG3205 (ジャイロ) + QMC5883L (磁気) |
| **軸数** | 9軸 (加速度3軸 + ジャイロ3軸 + 磁気3軸) |
| **インターフェース** | I2C |
| **動作電圧** | 3.0-5.5V |
| **消費電流** | 約 20mA |

---

## 構成センサー詳細

### ADXL345 (加速度センサー)

| 項目 | 仕様 |
|---|---|
| **軸数** | 3軸 (X, Y, Z) |
| **測定範囲** | ±2g / ±4g / ±8g / ±16g (設定可能) |
| **分解能** | 13-bit |
| **I2Cアドレス** | 0x53 |
| **サンプリングレート** | 最大 3200Hz |

### ITG3205 (ジャイロセンサー)

| 項目 | 仕様 |
|---|---|
| **軸数** | 3軸 (X, Y, Z) |
| **測定範囲** | ±2000°/s |
| **分解能** | 16-bit |
| **I2Cアドレス** | 0x68 |
| **サンプリングレート** | 最大 8kHz (内部), 出力 1kHz |

### QMC5883L (磁気センサー)

| 項目 | 仕様 |
|---|---|
| **軸数** | 3軸 (X, Y, Z) |
| **測定範囲** | ±8 Gauss |
| **分解能** | 16-bit |
| **I2Cアドレス** | 0x0D |
| **サンプリングレート** | 10-200Hz |

**注:** V1では HMC5883L を使用していたが、V2では QMC5883L に変更

---

## 配置

| 項目 | 仕様 |
|---|---|
| **実装基板** | CR Board (Compass Ring 背面) |
| **向き** | 背面（展示空間後方） |
| **用途** | 姿勢検出 / 方位測定 / 加速度検出 |

---

## I2C通信仕様

| 項目 | 仕様 |
|---|---|
| **I2Cバス** | I2C1系統 (HD ESP32-S3 #1) |
| **クロック周波数** | 100kHz |
| **プルアップ抵抗** | ESP32-S3内部プルアップ使用 |
| **バス長** | 最大15cm程度 (HD → PR → CR) |

**I2Cアドレス一覧:**

| センサー | I2Cアドレス |
|---|---|
| ADXL345 | 0x53 |
| ITG3205 | 0x68 |
| QMC5883L | 0x0D |

**接続経路:**
```
HD (ESP32-S3 #1) → PR取付機構 → CR Board → GY-85
  ↓
I2C1 (SDA/SCL)
```

---

## アドレス競合対策

**ステータス**: ✅ 解決済み

**参照コード:**
```
/Users/kyopan/Dropbox (個人)/Obsidian/kyopan/projects/fu/products/firmware/v1/Tube_v1/FU_TUBE_RP2040_U4/FU_TUBE_RP2040_U4.ino
```

**対策内容:**
- ADXL345 (0x53): 競合なし
- ITG3205 (0x68): I2C1系統で分離（GridEye 0x68 は I2C0）
- QMC5883L (0x0D): 競合なし

---

## 磁気センサー較正

| 項目 | 仕様 |
|---|---|
| **較正方法** | 使用しない |
| **理由** | 方位測定が主目的ではない |
| **用途** | 相対的な磁気変化検出のみ |

---

## データ読取例

### ADXL345 (加速度)

```cpp
// 加速度データ読取
int16_t accel_x = I2C_Read16(0x53, 0x32); // DATAX0, DATAX1
int16_t accel_y = I2C_Read16(0x53, 0x34); // DATAY0, DATAY1
int16_t accel_z = I2C_Read16(0x53, 0x36); // DATAZ0, DATAZ1

// ±2g 設定時の変換
float accel_x_g = accel_x * 0.004; // 3.9mg/LSB
```

### ITG3205 (ジャイロ)

```cpp
// ジャイロデータ読取
int16_t gyro_x = I2C_Read16(0x68, 0x1D); // GYRO_XOUT_H, GYRO_XOUT_L
int16_t gyro_y = I2C_Read16(0x68, 0x1F); // GYRO_YOUT_H, GYRO_YOUT_L
int16_t gyro_z = I2C_Read16(0x68, 0x21); // GYRO_ZOUT_H, GYRO_ZOUT_L

// 角速度変換
float gyro_x_dps = gyro_x / 14.375; // 14.375 LSB/(°/s)
```

### QMC5883L (磁気)

```cpp
// 磁気データ読取
int16_t mag_x = I2C_Read16(0x0D, 0x00); // Data Output X LSB, MSB
int16_t mag_y = I2C_Read16(0x0D, 0x02); // Data Output Y LSB, MSB
int16_t mag_z = I2C_Read16(0x0D, 0x04); // Data Output Z LSB, MSB
```

---

## 用途

| センサー | 用途 |
|---|---|
| **ADXL345** | 傾き検出 / 振動検出 / 衝撃検知 |
| **ITG3205** | 回転速度測定 / ジャイロドリフト補正 |
| **QMC5883L** | 磁気変化検出（較正なし） |

---

## 参考資料

- [ADXL345 Datasheet](https://www.analog.com/media/en/technical-documentation/data-sheets/ADXL345.pdf)
- [ITG3205 Datasheet](https://invensense.tdk.com/wp-content/uploads/2015/02/ITG-3200-Datasheet.pdf)
- [QMC5883L Datasheet](https://datasheet.lcsc.com/lcsc/2111151730_QST-QMC5883L_C192585.pdf)
- [V1 ファームウェア参照](../../firmware/v1/Tube_v1/FU_TUBE_RP2040_U4/FU_TUBE_RP2040_U4.ino)

---

## 決定事項

- [x] 構成センサー: ADXL345 + ITG3205 + QMC5883L
- [x] アドレス競合対策: I2C1系統で分離
- [x] 磁気較正: 使用しない
- [ ] CR Board上の実装位置決定
- [ ] データ処理アルゴリズム設計

---

## 変更履歴

| 日付 | 変更内容 | 担当 |
|---|---|---|
| 2025-11-09 | 初版作成（QMC5883L対応） | CIC |

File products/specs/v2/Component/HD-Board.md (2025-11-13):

# HD Board 仕様書

**作成日**: 2025-11-09
**ステータス**: 🔄 設計中

---

## 基本仕様

| 項目 | 仕様 |
|---|---|
| **基板名** | HD Board (Horozon Disc) |
| **形状** | 円形 |
| **直径** | 50-65mm（制約範囲） |
| **厚さ** | 1.6mm |
| **層数** | 4層 |
| **材質** | FR-4 |
| **表面処理** | ENIG (無鉛) 推奨 |

---

## 搭載部品

### マイコン

| 部品 | 数量 | 用途 |
|---|---|---|
| **ESP32-S3-MINI-1-N8** | 2個 | #1: WiFi/センサー統合<br/>#2: モーター/サーボ制御 |

### 電源

| 部品 | 数量 | 用途 |
|---|---|---|
| **TPS54202DDCR** | 1個 | 24V → 5V DCDC (2A) |
| **3.3V LDO** | 2個 | 5V → 3.3V (ESP32-S3用) |

### センサー

| 部品 | 数量 | 用途 |
|---|---|---|
| **AS5600** | 2個 | AS-S (スリップリング) + AS-Y (YAWモーター) |

### モーター・アクチュエーター

| 部品 | 数量 | 用途 |
|---|---|---|
| **DRV8311** | 1個 | BLDC YAWモーター ドライバ |
| **RCサーボ DS-M005** | 1個 | Pitch制御 |

### コネクタ

| 部品 | 数量 | 用途 |
|---|---|---|
| **4極ミニプラグ メス** | 1個 | Winch ↔ HD (24V/GND/TX/RX) |
| **FPC コネクタ** | 1個 | HD → PR (5V/GND/I2C0/I2C1/NeoPixel) |

---

## 実装レイアウト

### 配置方針

```
        [北]
         ↑
         │
    ┌────────┐
    │        │
[西]│   ●    │[東] ← サーボ: 右端（東側）
    │        │      未定部品: 左端（西側）
    └────────┘
         │
         ↓
       [南]
    YAWモーター
```

### サーボ配置

| 項目 | 仕様 |
|---|---|
| **位置** | HD右端（東側） |
| **向き** | サーボ軸が南向き（YAWモーター側） |
| **取付** | ネジ固定 or 基板穴固定 |

### 左端配置（検討中）

**候補部品:**
- DCDC Converter (TPS54202)
- DRV8311 (BLDC Driver)
- FPC コネクタ
- 予備スペース

**決定事項:**
- [ ] 左端配置部品の優先順位決定
- [ ] 熱源（DCDC, DRV8311）の配置最適化

---

## 層構成（4層）

| 層 | 用途 | 特記事項 |
|----|---|---|
| **L1 (Top)** | 信号・部品実装面 | 高密度配線 |
| **L2 (Inner)** | GND プレーン | ノイズシールド |
| **L3 (Inner)** | 電源プレーン (5V/3.3V) | 低インピーダンス |
| **L4 (Bottom)** | 信号・GND補強 | 部品実装可 |

**プレーン分割:**
- L2: アナログGND / デジタルGND 分離
- L3: 5V / 3.3V / 24V 分離

---

## 電源系統

### 電源フロー

```
24V (Winch) → DCDC (TPS54202) → 5V → LDO → 3.3V (ESP32-S3 × 2)
                                  ↓
                                NeoPixel (5V直接)
                                  ↓
                                RCサーボ (要検討: 5V or 3.7V)
```

### 電源レール

| レール | 電圧 | 電流 | 用途 |
|---|---|---|---|
| **24V** | 24V | 1.5A | DCDC入力 |
| **5V** | 5V | 2A | NeoPixel / サーボ / LDO入力 |
| **3.3V** | 3.3V | 500mA | ESP32-S3 × 2 / センサー |

---

## 信号系統

### I2C

| バス | 用途 | SDA | SCL |
|---|---|-----|-----|
| **I2C0** | GridEye (GR) | GPIO未定 | GPIO未定 |
| **I2C1** | GY-85 (CR) | GPIO未定 | GPIO未定 |
| **I2C (ESP32-S3 #2)** | AS5600 × 2 | GPIO未定 | GPIO未定 |

### UART

| 信号 | 用途 | GPIO |
|---|---|---|
| **TX** | HD → Winch | GPIO未定 |
| **RX** | Winch → HD | GPIO未定 |

### PWM

| 信号 | 用途 | GPIO |
|---|---|---|
| **Servo PWM** | RCサーボ制御 | GPIO未定 |
| **BLDC PWM × 3** | DRV8311 (U/V/W) | GPIO未定 × 3 |

### NeoPixel

| 信号 | 用途 | GPIO |
|---|---|---|
| **Data** | NeoPixel 96個制御 | GPIO未定 |

---

## FPC接続仕様

### HD → PR配線 (5線)

| 信号 | 電圧 | 電流 |
|---|---|---|
| 5V | 5V | 2A |
| GND | 0V | 2A |
| I2C0 SDA | 3.3V | - |
| I2C0 SCL | 3.3V | - |
| I2C1 SDA | 3.3V | - |
| I2C1 SCL | 3.3V | - |
| NeoPixel Data | 3.3V | - |

**コネクタ候補:**
- AFA07-S10FCC-00 (FPC 10pin)

---

## 熱設計

### 発熱源

| 部品 | 発熱量 (推定) |
|---|---|
| **TPS54202** | 0.5W |
| **DRV8311** | 1.0W |
| **ESP32-S3 × 2** | 0.5W × 2 = 1.0W |
| **合計** | 2.5W |

### 放熱対策

| 項目 | 仕様 |
|---|---|
| **銅箔面積** | 最大化（L2 GNDプレーン） |
| **サーマルビア** | 発熱部品下に配置 |
| **エアフロー** | 自然対流 |

---

## 決定事項

- [x] 基板形状: 円形
- [x] 直径範囲: 50-65mm
- [x] 厚さ: 1.6mm
- [x] 層数: 4層
- [x] サーボ配置: 右端
- [ ] 左端配置部品決定
- [ ] GPIO割当表作成
- [ ] 基板レイアウト設計
- [ ] 熱シミュレーション

---

## 参考資料

- [ESP32-S3 Hardware Design Guidelines](https://www.espressif.com/sites/default/files/documentation/esp32-s3_hardware_design_guidelines_en.pdf)
- [TPS54202 PCB Layout](https://www.ti.com/lit/an/slva559/slva559.pdf)

---

## 変更履歴

| 日付 | 変更内容 | 担当 |
|---|---|---|
| 2025-11-09 | 初版作成 | CIC |

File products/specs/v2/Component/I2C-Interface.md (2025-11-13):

# I2C Interface 仕様書

**作成日**: 2025-11-09
**ステータス**: ✅ 確定

---

## 基本仕様

| 項目 | 仕様 |
|---|---|
| **クロック周波数** | 100kHz (標準モード) |
| **プルアップ抵抗** | ESP32-S3内部プルアップ使用 |
| **バス長** | 最大15cm程度 |
| **動作電圧** | 3.3V (TTLレベル) |

---

## I2Cバス構成

### I2C0系統

| 項目 | 仕様 |
|---|---|
| **マスター** | ESP32-S3 #1 |
| **スレーブ** | GridEye AMG8833 (GR) |
| **I2Cアドレス** | 0x68 |
| **用途** | 赤外線アレイセンサーデータ取得 |

**接続経路:**
```
HD (ESP32-S3 #1) → PR取付機構 → GR Board → GridEye (0x68)
  ↓
I2C0 (SDA/SCL)
```

### I2C1系統

| 項目 | 仕様 |
|---|---|
| **マスター** | ESP32-S3 #1 |
| **スレーブ** | GY-85 (ADXL345, ITG3205, QMC5883L) |
| **I2Cアドレス** | 0x53 (ADXL345)<br/>0x68 (ITG3205)<br/>0x0D (QMC5883L) |
| **用途** | 9軸センサーデータ取得 |

**接続経路:**
```
HD (ESP32-S3 #1) → PR取付機構 → CR Board → GY-85
  ↓
I2C1 (SDA/SCL)
```

### I2C (ESP32-S3 #2用)

| 項目 | 仕様 |
|---|---|
| **マスター** | ESP32-S3 #2 |
| **スレーブ** | AS5600 × 2 (AS-S, AS-Y) |
| **I2Cアドレス** | 0x36 (両方とも) |
| **用途** | エンコーダー角度読取 |

**接続経路:**
```
ESP32-S3 #2 → AS5600 (AS-S) - スリップリング角度
            → AS5600 (AS-Y) - YAWモーター角度
```

**アドレス競合対策:**
- AS-S と AS-Y は**別々のI2Cバス**に接続（ESP32-S3 #2で2系統使用）

---

## クロック周波数

| モード | 周波数 | 選択 |
|---|---|---|
| **標準モード** | 100kHz | ✅ 採用 |
| **高速モード** | 400kHz | - |
| **高速モードPlus** | 1MHz | - |

**採用理由:**
- バス長15cm程度 → 100kHzで安定動作
- センサーデータレート（10fps, 1kHz等）に対して十分
- ノイズマージン確保

---

## プルアップ抵抗

### ESP32-S3内部プルアップ使用

| 項目 | 仕様 |
|---|---|
| **抵抗値** | 約 45kΩ (ESP32-S3内部) |
| **設定** | ソフトウェアで有効化 |
| **外部抵抗** | 不要（初期設定） |

```cpp
// ESP32-S3 内部プルアップ有効化
Wire.begin(SDA_PIN, SCL_PIN);
pinMode(SDA_PIN, INPUT_PULLUP);
pinMode(SCL_PIN, INPUT_PULLUP);
```

### 外部プルアップ（必要に応じて）

| 抵抗値 | 用途 |
|---|---|
| **2.2kΩ** | 高速通信・長距離バス |
| **4.7kΩ** | 標準的な用途 |
| **10kΩ** | 低速通信・短距離バス |

**追加条件:**
- バス長 > 30cm
- スレーブ数 > 3個
- ノイズ環境下

**決定事項:**
- [ ] 実機テストで内部プルアップの動作確認
- [ ] 必要に応じて外部2.2kΩ追加

---

## バス長とキャパシタンス

### バス長の影響

| バス長 | キャパシタンス (推定) | 100kHz動作 |
|---|---|---|
| **5cm** | ~10pF | ✅ 良好 |
| **15cm** | ~30pF | ✅ 良好 |
| **30cm** | ~60pF | ⚠️ 注意 |
| **50cm** | ~100pF | ❌ 推奨外 |

**V2での最大バス長:**
- HD → PR → GR/CR: 約15cm
- キャパシタンス: ~30pF → 100kHzで問題なし

---

## I2C通信フォーマット

### アドレス指定

```
START → [ADDR|R/W] → ACK → [DATA] → ACK → ... → STOP
```

| 項目 | ビット長 |
|---|---|
| **スレーブアドレス** | 7-bit |
| **R/W bit** | 1-bit (0=Write, 1=Read) |
| **データ** | 8-bit |

### 例: GridEye温度読取

```cpp
// 0x68: GridEye アドレス
// 0x80: 温度データレジスタ開始アドレス

Wire.beginTransmission(0x68);
Wire.write(0x80);           // レジスタ指定
Wire.endTransmission(false); // リピートスタート
Wire.requestFrom(0x68, 128); // 128 bytes 読取

uint8_t data[128];
for (int i = 0; i < 128; i++) {
  data[i] = Wire.read();
}
```

---

## エラー処理

### ACK/NACK処理

```cpp
uint8_t error = Wire.endTransmission();

if (error == 0) {
  // 成功
} else if (error == 2) {
  // スレーブアドレス NACK
  Serial.println("Device not found");
} else if (error == 3) {
  // データ NACK
  Serial.println("Data transmission failed");
}
```

### タイムアウト設定

```cpp
Wire.setTimeout(100); // 100ms タイムアウト
```

---

## 決定事項

- [x] クロック周波数: 100kHz
- [x] プルアップ抵抗: ESP32-S3内部プルアップ
- [x] バス長: 最大15cm程度
- [ ] 実機での通信安定性確認
- [ ] 外部プルアップ抵抗の必要性判断

---

## 参考資料

- [I2C Specification (NXP)](https://www.nxp.com/docs/en/user-guide/UM10204.pdf)
- [ESP32-S3 I2C API Reference](https://docs.espressif.com/projects/esp-idf/en/latest/esp32s3/api-reference/peripherals/i2c.html)

---

## 変更履歴

| 日付 | 変更内容 | 担当 |
|---|---|---|
| 2025-11-09 | 初版作成 | CIC |

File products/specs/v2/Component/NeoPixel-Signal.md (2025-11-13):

# NeoPixel Signal 仕様書

**作成日**: 2025-11-09
**ステータス**: ✅ 確定

---

## 基本仕様

| 項目 | 仕様 |
|---|---|
| **信号タイプ** | シリアル (1-wire) |
| **信号電圧** | 3.3V (ESP32出力) |
| **信号線最大長** | 30cm (HD → GR → CR) |
| **リフレッシュレート** | 400kHz |
| **データ線バッファIC** | 不使用 |
| **LED総数** | 96個 (GR 48個 + CR 48個) |

---

## 信号経路

```
HD (ESP32-S3 #1)
  ↓ (FPC)
PR取付機構
  ↓ (FPC/ハーネス)
GR Board → NeoPixel × 48 (前24 + 後24)
  ↓ (基板間配線)
CR Board → NeoPixel × 48 (前24 + 後24)
```

**総距離:**
- HD → PR: ~5cm (FPC)
- PR → GR: ~10cm (FPC/ハーネス)
- GR → CR: ~15cm (基板間配線)
- **合計: ~30cm**

---

## WS2812B タイミング仕様

### ビットタイミング

| 項目 | T0 (0-bit) | T1 (1-bit) |
|---|---|---|
| **HIGH時間** | 0.4μs ±0.15μs | 0.8μs ±0.15μs |
| **LOW時間** | 0.85μs ±0.15μs | 0.45μs ±0.15μs |
| **合計** | 1.25μs | 1.25μs |

### リセット信号

| 項目 | 仕様 |
|---|---|
| **リセット時間** | >50μs (LOW) |
| **用途** | 全LED更新完了後にラッチ |

---

## リフレッシュレート

**クロック周波数:** 400kHz

| 項目 | 計算 |
|---|---|
| **1ビット時間** | 1 / 400kHz = 2.5μs |
| **1ピクセル** | 24 bits × 2.5μs = 60μs |
| **96ピクセル** | 96 × 60μs = 5.76ms |
| **リセット時間** | 50μs |
| **1フレーム時間** | 5.76ms + 50μs = 5.81ms |
| **最大fps** | 1 / 5.81ms = **172 fps** |

**実用fps:**
- 60fps: 余裕あり ✅
- 100fps: 余裕あり ✅
- 172fps: 理論上限

---
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

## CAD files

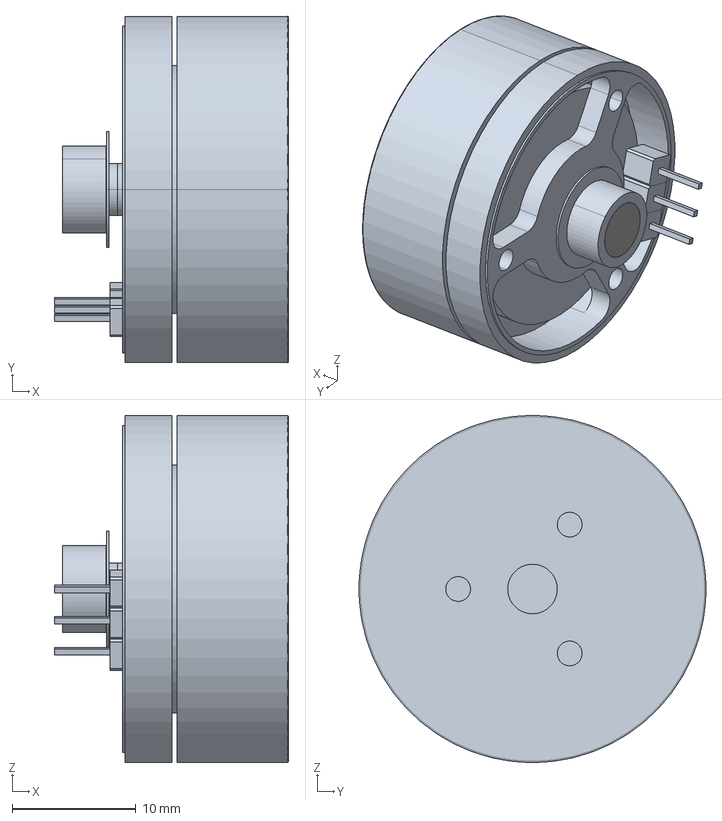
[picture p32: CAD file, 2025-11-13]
products/modeling/Assets/BLDC2206.stp
18.9 x 28.0 x 28.0 mm

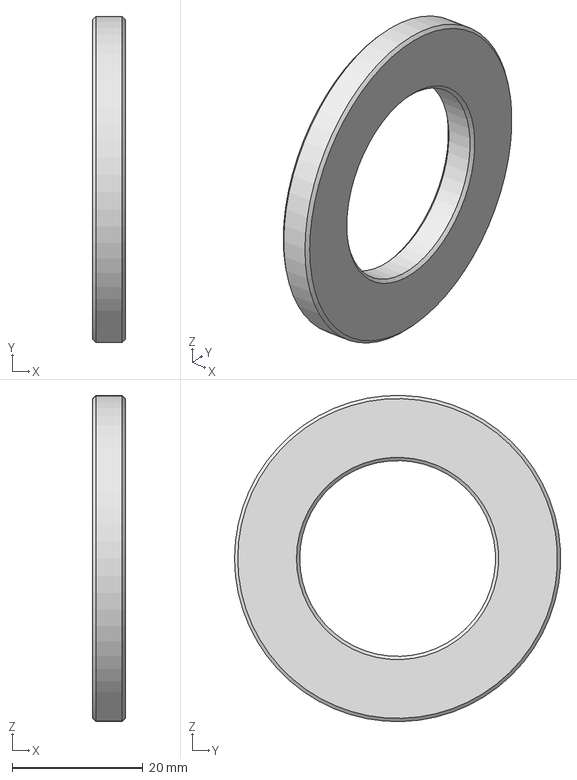
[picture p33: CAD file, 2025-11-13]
products/modeling/component/WSSB50-30-5.stp
5.00 x 50.0 x 50.0 mm

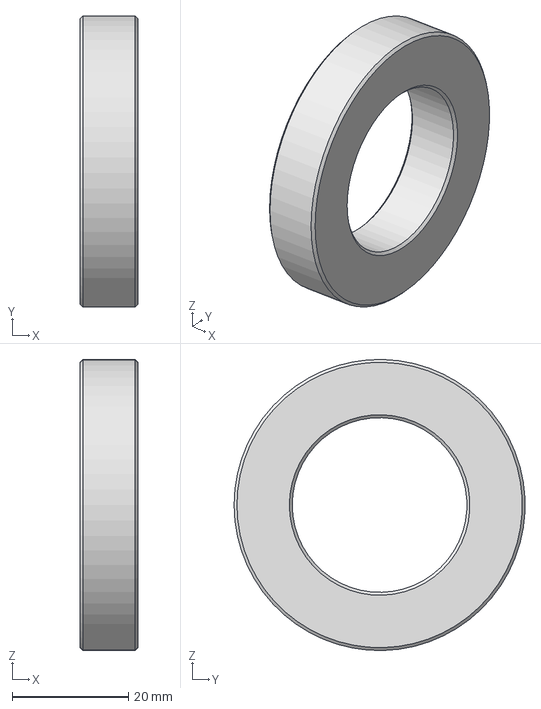
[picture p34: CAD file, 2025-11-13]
products/modeling/Assets/WSSB50-30-10.stp
10.0 x 50.0 x 50.0 mm

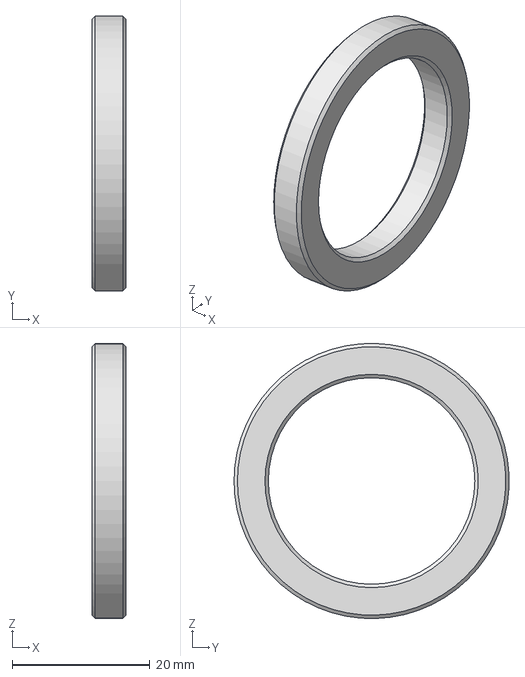
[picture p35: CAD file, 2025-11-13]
products/modeling/component/WSSB40-30-5.stp
5.00 x 40.0 x 40.0 mm

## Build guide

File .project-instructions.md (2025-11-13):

# FU Project - Local Rules

**プロジェクト**: Fragmentations of Unity - Nagoya Installation
**作成日**: 2025-11-13

---

## 絶対ルール

### 1. 仕様変更時のSpec更新義務

**原則**: 設計変更・仕様変更が発生した場合、**必ず対応するspecファイルを更新すること**

**対象ファイル:**
- `products/specs/v2/architect_v2/tube-v2-circuit-design.md` - 回路設計仕様
- `products/specs/v2/Component/` 配下の各コンポーネント仕様書
- 機構・機能に影響する全ての仕様書

**更新タイミング:**
1. ハードウェア変更（モーター、センサー、基板レイアウト等）
2. GPIO割当変更
3. 制御方式変更（制御アルゴリズム、PIDパラメータ等）
4. 電源系統変更
5. 通信プロトコル変更
6. 機構設計変更

**更新内容:**
- システム構成図（Mermaid図）
- コンポーネント仕様表
- GPIO割当表
- 消費電力試算
- 制御方式説明
- 決定事項チェックリスト
- 変更履歴

**手順:**
1. 実装・テストコード作成
2. 動作確認完了
3. **必ずspecファイルを更新**（このステップを飛ばしてはいけない）
4. 変更履歴に日付・変更内容・担当者を記録

**違反の影響:**
- ドキュメントと実装の乖離が発生
- 将来の保守性が著しく低下
- チーム内での情報共有に支障
- 回路設計ミス・実装ミスの原因となる

---

## 例: Pitch制御変更時の対応

**変更内容**: RCサーボ → BLDCモーター + 可変抵抗

**更新したspec箇所:**
1. V1からの主要変更点表（`Pitch制御`列）
2. コンポーネント仕様書リンク（モーター、角度センサー追加）
3. システム構成図（Mermaid図）
   - サーボノード削除
   - BLDCモーター・可変抵抗ノード追加
   - GPIO接続線追加
4. Core担当処理表（ESP32-S3 #2 Core1）
5. 消費電力試算
6. センサー接続表
7. Pitch Ring (PR) セクション全体
8. 変更履歴

**結果**: ドキュメントと実装の完全一致を維持

---

## 補足

このルールはkyopanプロジェクト全体の原則「ドキュメント駆動開発」を具体化したものです。
実装→ドキュメント更新という順序を厳守することで、プロジェクトの持続可能性を確保します。

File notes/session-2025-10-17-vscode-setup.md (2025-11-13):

# セッション記録: VS Code開発環境セットアップ

**日付**: 2025-10-17
**プロジェクト**: FU@ComoNe Winch U1 Firmware
**目的**: VS Code + PlatformIOでの開発準備完了

---

## 📋 セッション概要

VS Codeで新しいセッションを開いてPlatformIO開発を行うための完全なセットアップを実施。

**開発ディレクトリ**: `projects/nagoya-tube-installation/firmware/Winch/U1/`

---

## ✅ 作成したファイル

### 1. 開発指示書

**ファイル**: `.claude/instructions.md`

**内容**:
- 開発目的と期限（2025-10-24）
- 5つのフェーズ別タスクリスト
- ピンアサイン確定手順
- ファームウェア修正チェックリスト
- ビルド・書き込み・テスト手順（コード例付き）
- トラブルシューティング（WiFi, MQTT, I2C, UART, ビルドエラー）
- 完了条件

**特徴**:
- 具体的なコード例を多数含む
- I2C/UART通信のテストコード完備
- シリアルモニター出力の期待値を明記
- 各フェーズの成功基準を明確化

---

### 2. Claude設定ファイル

**ファイル**: `.claude/claude_config.json`

**内容**:
- プロジェクト基本情報
- 参照ドキュメントリスト（優先度付き）
- 開発環境情報（Framework, Board, Version）
- 5フェーズのタスク構造
- I2C/UART/MQTTテスト仕様
- 重要な注意事項
- コーディングスタイル

**特徴**:
- JSON形式で機械可読
- テスト仕様を構造化
- I2Cコマンド一覧を完備
- UARTコマンドフォーマットを明記

---

### 3. VS Code設定

**ファイル**: `.vscode/settings.json`（既存ファイル更新）

**追加設定**:
- Arduino/PlatformIO用ファイル関連付け（.ino, .h → cpp）
- フォーマット設定（Google Style, 2スペース）
- PlatformIO自動ビルド無効化
- .pioディレクトリ除外（検索・監視）
- C/C++フォーマッター設定

**効果**:
- コード編集がスムーズに
- 不要なビルドを抑制
- 大量のビルド成果物をVS Codeが監視しない

---

### 4. README.md

**ファイル**: `README.md`

**内容**:
- クイックスタートガイド（3ステップ）
- 開発環境セットアップ
- 主要タスク一覧（Phase 1-5）
- テストコマンド例（I2C/UART）
- プロジェクト構造
- 関連ドキュメントリンク
- 完了基準チェックリスト

**特徴**:
- 初めて開く人でもすぐに開発開始できる
- コピペで使えるテストコード
- 視覚的に分かりやすいタスク進捗表示

---

## 🎯 開発フロー

### VS Codeセッション開始手順

1. **ディレクトリを開く**
   ```bash
   cd /Users/kyopan/Dropbox (個人)/Obsidian/kyopan/projects/nagoya-tube-installation/firmware/Winch/U1
   code .
   ```

2. **開発指示書を確認**
   - `.claude/instructions.md` を開く
   - 現在のフェーズとタスクを確認

3. **ファームウェア仕様を確認**（必要に応じて）
   - `U1_FIRMWARE_OVERVIEW.md` で機能詳細を確認
   - `../../docs/specs/winch-u1-esp32s3-pinout.md` でピン配置を確認

4. **開発開始**
   - Phase 1から順に作業
   - 各タスク完了後にチェックボックスをオン

---

## 📚 ドキュメント階層

```
開発指示書（.claude/instructions.md）
    ├─ クイックリファレンス（README.md）
    ├─ 完全仕様（U1_FIRMWARE_OVERVIEW.md）
    ├─ ピンアサイン（winch-u1-esp32s3-pinout.md）
    ├─ 回路設計（winch-circuit-design.md）
    └─ V1分析（v1-analysis.md）
```

**読む順序**:
1. `.claude/instructions.md` - 開発タスク把握
2. `README.md` - クイックスタート
3. `U1_FIRMWARE_OVERVIEW.md` - 機能詳細（必要に応じて）

---

## 🔧 開発タスク（Phase別）

### Phase 1: ピンアサイン確定
**所要時間**: 1-2時間

- [ ] 基板回路図確認（EasyEDA/KiCad）
- [ ] ESP32-S3周辺トレース追跡
- [ ] U2 I2C接続確認（GPIO 8/9）
- [ ] U3 UART接続確認（GPIO 17/18）
- [ ] `winch-u1-esp32s3-pinout.md` 更新

**成果物**: ピンアサイン最終決定表

---

### Phase 2: ファームウェア修正
**所要時間**: 1-2時間

- [ ] `main.cpp`: GPIO番号定義確認・修正
- [ ] `main.cpp`: `Wire.begin(SDA, SCL)` 引数確認
- [ ] `main.cpp`: `Serial1.begin(baud, config, RX, TX)` 引数確認
- [ ] `platformio.ini`: ビルド設定確認

**成果物**: 修正済みソースコード

---

### Phase 3: ビルド＆書き込み
**所要時間**: 30分-1時間

- [ ] `pio run` でビルド成功
- [ ] `pio run --target upload` で書き込み成功
- [ ] `pio device monitor` でシリアル出力確認

**成功基準**:
```
WiFi接続成功
MQTT接続成功
ID取得開始
```

---

### Phase 4: 通信テスト
**所要時間**: 2-3時間

#### I2C通信テスト
- [ ] U2デバイス検出
- [ ] ホーミング状態読み取り
- [ ] 位置制御（1000mm送信）
- [ ] ダウンライト（50%送信）

#### UART通信テスト
- [ ] 統合データパケット送信
- [ ] LED色変化確認（赤→緑→青）
- [ ] Sparkコマンド送信
- [ ] Sparkアニメーション確認

#### システム統合テスト
- [ ] MQTT経由LED制御
- [ ] MQTT経由位置制御
- [ ] MQTT経由Sparkモード

**成果物**: テスト結果ログ

---

### Phase 5: ドキュメント更新
**所要時間**: 30分

- [ ] `winch-u1-esp32s3-pinout.md` にテスト結果追記
- [ ] `../../TODO.md` の各サブタスクをチェック
- [ ] TODO集約スクリプト実行

**コマンド**:
```bash
cd /Users/kyopan/Dropbox (個人)/Obsidian/kyopan
python3 .todos/sync-todos.py
```

---

## 🧪 テストコード例

### I2C通信テスト関数

```cpp
void testI2CConnection() {
  Serial.println("=== I2C Communication Test ===");

  // ホーミング状態読み取り
  Wire.requestFrom(U2_SLAVE_ADDRESS, 2);
  if (Wire.available() == 2) {
    char tag = Wire.read();
    int status = Wire.read();
    Serial.printf("[TEST] Homing: tag='%c', status=%d\n", tag, status);
  }

  // 位置制御（1000mm）
  Wire.beginTransmission(U2_SLAVE_ADDRESS);
  Wire.write('Z');
  Wire.write(0xE8);  // LSB
  Wire.write(0x03);  // MSB
  byte err = Wire.endTransmission();
  Serial.printf("[TEST] Position (1000mm): err=%d\n", err);

  Serial.println("=== I2C Test Complete ===");
}
```

### UART通信テスト関数

```cpp
void testUARTConnection() {
  Serial.println("=== UART Communication Test ===");

  // 赤色LED
  Serial1.printf("DATA,F,255,0,0,R,0,0,0,P,0.00,0.00,B,0,H,0.00\n");
  delay(1000);

  // 緑色LED
  Serial1.printf("DATA,F,0,255,0,R,0,0,0,P,0.00,0.00,B,0,H,0.00\n");
  delay(1000);

  // 青色LED
  Serial1.printf("DATA,F,0,0,255,R,0,0,0,P,0.00,0.00,B,0,H,0.00\n");
  delay(1000);

  // Sparkモード（10秒）
  Serial1.printf("SPARK,10\n");

  Serial.println("=== UART Test Complete ===");
}
```

### setup()への追加

```cpp
void setup() {
  // ... 既存のセットアップコード ...

  // テスト実行（開発中のみ）
  testI2CConnection();
  testUARTConnection();
}
```

---

## 🐛 トラブルシューティング

### よくある問題と解決策

#### 問題1: I2C error=2 (NACK on address)

**原因**: U2デバイスが応答しない

**解決策**:
1. U2の電源確認
2. I2Cプルアップ抵抗確認（4.7kΩ）
3. SDA/SCL配線確認（逆接続していないか）
4. スレーブアドレス確認（0x08）

---

#### 問題2: UARTでLEDが反応しない

**原因**: TX/RX配線または設定ミス

**解決策**:
1. TX/RX配線確認（クロス接続が必要な場合あり）
2. ボーレート確認（38400 baud）
3. U3の電源確認
4. シリアルモニターでパケット送信を確認

---

#### 問題3: WiFi接続失敗

**原因**: SSID/パスワード不一致

**解決策**:
1. `main.cpp` のWiFi設定確認
2. WiFiルーター電波強度確認
3. ESP32-S3アンテナ接続確認

---

## 📊 期待される開発時間

| Phase | タスク | 所要時間 |
|---|---|---|
| 1 | ピンアサイン確定 | 1-2時間 |
| 2 | ファームウェア修正 | 1-2時間 |
| 3 | ビルド＆書き込み | 0.5-1時間 |
| 4 | 通信テスト | 2-3時間 |
| 5 | ドキュメント更新 | 0.5時間 |
| **合計** | | **5-9時間** |

**推奨スケジュール**: 2日間（各4-5時間）

---

## 🔗 関連ファイル

### 作成・更新されたファイル

```
firmware/Winch/U1/
├── .claude/
│   ├── instructions.md       # 新規作成
│   └── claude_config.json    # 新規作成
├── .vscode/
│   └── settings.json         # 更新
├── README.md                 # 新規作成
├── U1_FIRMWARE_OVERVIEW.md   # 既存（参照用）
└── src/
    └── main.cpp              # 修正予定
```

### 参照ドキュメント

```
docs/specs/
├── winch-u1-esp32s3-pinout.md    # ピンアサイン仕様
└── winch-circuit-design.md        # 回路設計仕様

notes/
├── v1-analysis.md                 # V1システム分析
└── session-2025-10-17-firmware-integration.md  # 前セッション記録

TODO.md                            # プロジェクト全体TODO
```

---

## ✅ 完了条件

- [x] `.claude/instructions.md` 作成
- [x] `.claude/claude_config.json` 作成
- [x] `.vscode/settings.json` 更新
- [x] `README.md` 作成
- [ ] VS Codeで開発セッション開始
- [ ] Phase 1-5のタスク完了
- [ ] TODO.md更新・集約

---

## 🎯 次のアクション

1. **VS Codeを開く**
   ```bash
   cd /Users/kyopan/Dropbox (個人)/Obsidian/kyopan/projects/nagoya-tube-installation/firmware/Winch/U1
   code .
   ```

2. **開発指示書を確認**
   - `.claude/instructions.md` を開く

3. **Phase 1から開始**
   - 基板回路図の確認
   - ピンアサイン確定

4. **Claude/Copilotと協働**
   - テストコードの実装
   - デバッグ支援
   - ドキュメント更新

---

**VS Code開発環境の準備が完了しました。新しいセッションを開いて開発を開始してください！**

**記録者**: Claude (CIC - Context Integration Coordinator)

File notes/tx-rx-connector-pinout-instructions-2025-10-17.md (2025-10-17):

# TX/RXピンアサインとコネクタピン配置の指示

**日付**: 2025-10-17
**音声ファイル**: [tx-rx-connector-pinout-2025-10-17.m4a](audio-transcriptions/tx-rx-connector-pinout-2025-10-17.m4a)
**プロジェクト**: FU@ComoNe (名古屋チューブインスタレーション)
**対象**: 評価ボード設計（Grid Ring, Pitch Ring, GY85 Ring）

---

## 📋 要旨

UART通信（TX/RX）のピンアサインとシルク印刷の表記、4極ステレオジャックのピン配置順序について、重要な設計指示。

---

## 🔌 UART通信の基本原則

### TX/RXクロス接続の重要性

**マイコンA ↔ マイコンB の接続:**

```
マイコンA の TX → マイコンB の RX
マイコンA の RX → マイコンB の TX
```

- **TX (Transmit)**: 送信ピン
- **RX (Receive)**: 受信ピン
- **必ずクロス接続**: TX同士、RX同士を接続すると通信不可、最悪の場合ピン破損の可能性

### Primary/Secondary (旧Master/Slave) の考え方

- **Primary (プライマリー)**: メインマイコン（今回はウィンチ側）
- **Secondary (セカンダリー)**: サブマイコン（今回は筒・評価ボード側）

**今回の構成:**
- **Primary**: ウィンチ（鈴木さん担当）
- **Secondary**: 筒・評価ボード（Grid Ring, Pitch Ring, GY85 Ring）

---

## 🎯 評価ボード側の設計指示

### シルク印刷の表記方法

**Secondary側（筒・評価ボード）のPCBには以下のようにシルク印刷:**

#### 4極ステレオジャック付近のシルク表記

```
TX from Winch  →  (RP2040のRXピンに接続)
RX from Winch  →  (RP2040のTXピンに接続)
```

または

```
TX ← (矢印でウィンチ方向を示す)
RX ← (矢印でウィンチ方向を示す)
```

**ポイント:**
- ジャック側には「ウィンチから来るTX」「ウィンチから来るRX」と表記
- これをRP2040のRX/TXに**クロス接続**する
- Secondary側のPCBだけ見ても接続が明確になる

---

## 🔧 4極ステレオジャックのピン配置順序

### 推奨ピン配置（安全性重視）

#### 現在の一般的な配置
```
先端 (Tip)       → GND
リング1 (Ring1)  → 24V
リング2 (Ring2)  → TX
根元 (Sleeve)    → RX
```

#### **推奨配置（安全性向上）**

```
先端 (Tip)       → 24V
リング1 (Ring1)  → TX
リング2 (Ring2)  → RX
根元 (Sleeve)    → GND
```

**理由:**

1. **抜き差し時の安全性**
   - プラグを差し込む際、先端から順に接触していく
   - 現在の配置（先端=GND）だと、24Vが先にショートする可能性
   - 推奨配置（根元=GND）なら、最後にGNDが接触するため安全

2. **24Vの攻撃性**
   - 24Vは高電圧なので、接触不良時の火花や短絡リスクが高い
   - 最後に接触する根元（Sleeve）をGNDにすることで、24Vの誤接触リスクを低減

3. **通信信号の保護**
   - TX/RXは中間のリング1, 2に配置
   - GNDとのショートリスクを最小化

---

## ✅ 設計チェックリスト

### Secondary側（評価ボード）PCB設計

- [ ] **4極ステレオジャックのピン配置**
  - [ ] 先端 (Tip) = 24V
  - [ ] リング1 = TX (from Winch)
  - [ ] リング2 = RX (from Winch)
  - [ ] 根元 (Sleeve) = GND

- [ ] **シルク印刷**
  - [ ] ジャック付近に「TX from Winch」「RX from Winch」と表記
  - [ ] または矢印でウィンチ方向を明示

- [ ] **RP2040ピンアサイン**
  - [ ] ジャックの「TX from Winch」→ RP2040の**RX (GPIO1)**
  - [ ] ジャックの「RX from Winch」→ RP2040の**TX (GPIO0)**
  - [ ] クロス接続を確認

- [ ] **ESD保護回路**
  - [ ] TX/RXラインにESD保護回路を追加

---

## 📝 補足事項

### Primary側（ウィンチ）の設計

- ウィンチ側（鈴木さん担当）のシルク印刷は変更不要
- ウィンチのマイコンTXは「TX」、RXは「RX」と表記されているはず
- Secondary側で正しくクロス接続されていれば問題なし

### 他のプロジェクトへの適用

この原則は他のUART通信を使用するプロジェクトでも適用可能：
- Primary/Secondaryの明確化
- Secondary側のシルク表記で「from Primary」と明示
- コネクタピン配置の安全性考慮（電源ピンを最後に接触）

---

## 🔗 関連ドキュメント

- [評価ボード設計タスク](../docs/tasks/evaluation-board-design.md)
- [Winch V2回路設計仕様](../docs/specs/winch-circuit-design.md)
- [V1システム分析](v1-analysis.md)

---

**音声文字起こし完了日**: 2025-10-17
**次のアクション**: 評価ボード設計（Grid Ring, Pitch Ring, GY85 Ring）に反映

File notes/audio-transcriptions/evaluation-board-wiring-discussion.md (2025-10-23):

# 評価ボード配線ディスカッション

**日時**: 2025-10-23 10:52
**音声**: recording-2025-10-23-evaluation-board.m4a（約20分）
**参加者**: kyopan、鈴木さん（設計担当）
**関連資料**: [evaluation-board-sketch.jpg](../evaluation-board-sketch.jpg)

## 議論の目的

- 表裏基板の配線問題を解決
- 今日中に発注したい
- 組み付けコストを最小化

## 現状の問題点

### ミラーリングによる配線の複雑化

- 現状: ピッチリング（PR）とグリッドアイリング（GR）、コンパスリング（CR）が反転している
- メイン基板の上から見た構造:
  - ピッチリング: 5V + GND（グランド）が上部2箇所
  - この配置が反転すると、GRとGRが隣接し、配線がクロスして複雑化

### 配線の複雑性

- GRの配線がクロスする問題
- 基板の配置上の反転により、配線トポロジーが複雑になる

## 提案された解決策

### 1. 同じトポロジーで統一（ミラーリング不要）

**基本コンセプト**: ピッチリング、GR、CRを同じ向きで設計

- **PRF（Pitch Ring Front）** と **PRR（Pitch Ring Rear）**
- **GRF（Grideye Ring Front）** と **GRR（Grideye Ring Rear）**
- **CRF（Compass Ring Front）** と **CRR（Compass Ring Rear）**

従来は F/R が逆配線だったが、これを共通化する。

**重要**: GRとCRはそれぞれGrideyeとCompass（GY85）が乗るが、**共通基板を使用**する。

### 2. センサーの配置

- **GRF**: Grideyeを配置
- **CRR**: GY85（Compass）を配置

**注意**: GRとCRは共通基板のため、センサーは表裏で配置される。これにより配線がシンプルになる。

### 3. 真鍮線配線の詳細

#### 貫通配線（全リング共通）

- **真鍮線3 (Power)**: 5V - GR↔PR↔CR（LED/センサ電源供給用）
- **真鍮線4 (Power)**: GND - GR↔PR↔CR（LED/センサ電源供給用）
- **真鍮線1 (NeoPixel)**: PRR.NEOs2.DOUT → GRF.NEOs3.DIN
- **真鍮線2 (NeoPixel)**: GRR.NEOs4.DOUT → CRF.NEOs5.DIN

#### 部分配線（PR↔GR間のみ）

I2C通信用の個別配線:
- **真鍮線5 (I2C)**: PR.Grideye.SDA0 → GR.Grideye.SDA0
- **真鍮線6 (I2C)**: PR.Grideye.SCL0 → GR.Grideye.SCL0
- **真鍮線7 (I2C)**: PR.Compass.SDA1 → GR.Compass.SDA1
- **真鍮線8 (I2C)**: PR.Compass.SCL1 → GR.Compass.SCL1

#### 懸念点

- **真鍮線1**: CRにも接続されている可能性があり、データ衝突の懸念
- **真鍮線2**: PRを貫通しているが、電気的に接続していなければ問題ない

## ネオピクセル配線の詳細

### LED点灯パターン

1. **PRF** → 24個のNEOs1を点灯
2. **PRR** → 24個のNEOs2を点灯
3. PRR → **GRF** → 24個のNEOs3を点灯
4. GRF → **GRR** → 24個のNEOs4を点灯
5. GRR → **CRF** → 24個のNEOs5を点灯
6. CRF → **CRR** → 24個のNEOs6を点灯

### 配線の流れ

```
RP2040 GPIO29 → NEOs1 (PRF, 24LEDs)
             → NEOs2 (PRR, 24LEDs)
             → [真鍮線1] → NEOs3 (GRF, 24LEDs)
             → NEOs4 (GRR, 24LEDs)
             → [真鍮線2] → NEOs5 (CRF, 24LEDs)
             → NEOs6 (CRR, 24LEDs)
```

### 真鍮線の詳細仕様

#### NeoPixel用（信号線）

- **真鍮線1 (NeoPixel)**: PRR.NEOs2.DOUT → GRF.NEOs3.DIN
  - 懸念: CRにも接続されている可能性があり、データ衝突の懸念
- **真鍮線2 (NeoPixel)**: GRR.NEOs4.DOUT → CRF.NEOs5.DIN
  - 注意: PRを貫通しているが、電気的に接続していなければ問題ない

#### 電源用（貫通配線）

- **真鍮線3 (Power)**: 5V - GR↔PR↔CR（LED/センサ電源供給用）
- **真鍮線4 (Power)**: GND - GR↔PR↔CR（LED/センサ電源供給用）

#### I2C用（部分配線: PR↔GR間のみ）

- **真鍮線5 (I2C)**: PR.Grideye.SDA0 → GR.Grideye.SDA0
- **真鍮線6 (I2C)**: PR.Grideye.SCL0 → GR.Grideye.SCL0
- **真鍮線7 (I2C)**: PR.Compass.SDA1 → GR.Compass.SDA1
- **真鍮線8 (I2C)**: PR.Compass.SCL1 → GR.Compass.SCL1

### 共通基板の設計

**基板構成:**
- GRとCRは**同じ基板を使用**（表裏でハンダ付け）
- **GRF**: Grideyeを配置（表面）
- **CRR**: GY85（Compass）を配置（裏面）

**懸念点:**
- NEOs6.DOUT が真鍮線1または真鍮線2にぶつかると、データが衝突する可能性
- 対処: 真鍮線2を分断する必要があるかもしれない

**確認事項:**
- 同じ基板をGRとCRで使用した場合、貫通配線が通信上問題ないか
- センサー配置（GRF: Grideye / CRR: GY85）が機械的・電気的に干渉しないか

## ハンダ付けと組み付けの順序

### 提案された手順

1. **PRを先に取り付け**
2. **真鍮線1〜8を通す**
   - 貫通配線: 真鍮線1, 2, 3, 4（全リング貫通）
   - 部分配線: 真鍮線5, 6, 7, 8（PR↔GR間のみ）
3. **GRとCRを軸化中に固定**
4. **ハンダ付け**
5. **真鍮線がカーブしてもOK**（無理に直線にしない）

### 懸念点: 応力による接続の信頼性

- 常に曲げた状態で力がかかると、ハンダ接合部に負荷
- 2年間の使用を考慮すると、何の力もかからない状態が理想
- 必要に応じて「折る」処理が必要かもしれない

## 決定事項

### 確定した配線

#### 貫通配線（全リング共通）

1. **真鍮線3 (Power)**: 5V - GR↔PR↔CR
2. **真鍮線4 (Power)**: GND - GR↔PR↔CR
3. **真鍮線1 (NeoPixel)**: PRR.NEOs2.DOUT → GRF.NEOs3.DIN（※CRへの接続懸念あり）
4. **真鍮線2 (NeoPixel)**: GRR.NEOs4.DOUT → CRF.NEOs5.DIN（※PRを貫通）

#### 部分配線（PR↔GR間のみ）

5. **真鍮線5 (I2C)**: PR.Grideye.SDA0 → GR.Grideye.SDA0
6. **真鍮線6 (I2C)**: PR.Grideye.SCL0 → GR.Grideye.SCL0
7. **真鍮線7 (I2C)**: PR.Compass.SDA1 → GR.Compass.SDA1
8. **真鍮線8 (I2C)**: PR.Compass.SCL1 → GR.Compass.SCL1

### 次のステップ

1. **鈴木さんに依頼**:
   - Pitch Ringのミラー設計を廃止
   - Grideye RingとCompass Ringで同じ基板を使用する設計
   - 貫通配線による組み付けコスト削減

2. **kyopanが実施**:
   - CICによる解析（同じ基板で通信上問題ないか検証）
   - ネオピクセル配線の詳細検証

3. **シンプル化の方向性**:
   - 以前のフィージビリティ検証でシンプルな設計が確認済み
   - この方向で進める

## 添付資料

- [evaluation-board-sketch.jpg](../evaluation-board-sketch.jpg) - 手書きスケッチ
- Document EVAL: 上部に配線構成図、下部に複数のSVG/CAD検討案

## メモ

- SOPA-5.0（5mm厚）とSOPA-3.0（3mm厚）の比較検討
- M5ネジ、M2コネクタの配置
- Grideye RingとCompass Ringのボード固定方法（R、Lの配置）

---

# ⚠️ 重要な設計変更（2025-10-23 午後）

**日時**: 2025-10-23 13:09
**音声**: recording-2025-10-23-neopixel-wiring-fix.m4a（約3分半）
**参加者**: kyopan

## 🚨 緊急修正: 真鍮線1（貫通配線）の問題

### 問題発見

**午前中の設計の問題点**:
```
真鍮線1 (NeoPixel信号線) - 貫通配線:
  PRR.NEOs2.DOUT → GRF.NEOs3.DIN → CRF.NEOs5.DIN
```

**重大な問題**:
- 真鍮線1が**貫通配線**（全リング共通配線）になっている
- PRからの信号が**GRとCRに同時に伝わる**
- **個別制御ができない**（GRとCRが同時に光ってしまう）

**結論**: **真鍮線1の貫通配線はやるべきではない**

---

## ✅ 修正内容: 部分配線への切り替え

### 変更後の仕様

#### 真鍮線1を部分配線化

```
変更前（貫通配線）:
  真鍮線1: PRR.NEOs2.DOUT → GRF.NEOs3.DIN → CRF.NEOs5.DIN
  → GRとCRが同時点灯（NG）

変更後（部分配線）:
  真鍮線1: PRR.NEOs2.DOUT → GRF.NEOs3.DIN
  → PR ↔ GR のみ接続、CRには接続しない（OK）
```

---

## 🔧 実装詳細

### 1. PRの配線変更

**変更箇所**:
- **PRのDINとDOUTを変更**
- CRとGRは変更不要

**配線最適化**:
- 真鍮線1をPRR.NEOs2.DOUTの**最も近い位置**に配線し直す
- **現状**: 最も離れた位置 → 余計な配線コスト発生
- **改善**: 最短距離で配線 → コスト削減

### 2. PRの真鍮線1端子を2端子化

**仕様**:
```
PR真鍮線1: 2つの端子を用意
  - 端子1: GRとの接続用
  - 端子2: CRとの接続用
```

**ジャンパー設定**:
- どちらのリング（GR or CR）と接続するかを**ジャンパーで選択**
- 必ずCR側と比較して共有設定を行う

---

## 🏷️ シルクラベル改善

### 基板ラベル表記ルール

#### 単独リング基板（PRのみ、GRのみ、CRのみ）

**表記**:
- 大きめに「**PRR**」「**PRF**」等を記載
- 裏と表で明確に区別

**例**:
```
表面: PRF (Pitch Ring Front)
裏面: PRR (Pitch Ring Rear)
```

#### 共通基板（GR-CR共用）

**推奨表記（表裏分離方式）**:
```
表面: GRF (Grideye Ring Front)
裏面: CRF (Compass Ring Front)

または

表面: GRR (Grideye Ring Rear)
裏面: CRR (Compass Ring Rear)
```

**理由**: センサーが変わるため、表裏で使い分けた方が分かりやすい

**代替表記（共通明示方式）**:
```
表面: CRF-GRF (共通基板)
裏面: CRR-GRR (共通基板)
```

### シルクラベルサイズ

**要件**:
- **もうちょっとでかめ**にできると良い
- 現場での視認性向上

---

## 📋 修正指示サマリー（鈴木さんへ）

### 優先度：高

1. ✅ **真鍮線1を部分配線に変更**
   - PR ↔ GR のみ接続
   - CRへの貫通配線を削除

2. ✅ **PRの配線最適化**
   - 真鍮線1端子位置をPRR.NEOs2.DOUTの最寄りに変更
   - 配線コスト削減

3. ✅ **PR真鍮線1端子を2端子化**
   - GR接続用とCR接続用
   - ジャンパーで選択可能に

4. ✅ **シルクラベル改善**
   - PRR/PRF/GRF/CRF等を大きく表示
   - 表裏の区別を明確化

### 次のアクション

**鈴木さんへの依頼**:
> 一旦ちょっと進めてもらってください。

---

## 🔗 更新履歴

- **2025-10-23 10:52**: 初版作成（20分音声ディスカッション）
- **2025-10-23 13:09**: 真鍮線1部分配線化修正追加（3分半音声メモ）

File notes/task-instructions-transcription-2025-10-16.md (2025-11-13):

# タスク指示 文字起こし（2025-10-16）

## 音声ファイル

- [task-instructions-2025-10-16.m4a](task-instructions-2025-10-16.m4a)
- [task-instructions-followup-2025-10-16.m4a](task-instructions-followup-2025-10-16.m4a)

## 文字起こし結果

### 新規録音 32.m4a（メインタスク指示）

中村中部インサルエッションについて進めます まず目的目的は10月の初かまでに ウィンチにと46代と2つ46代を作って 脳品する現時点ではウィンチがほぼ完成しているただし 普通に関してはもうちょっと時間かかるしまだ見つもるていない このため今大事なことはウィンチがちゃんと現場でワークするかをなるべく早く確かめたいそのために10月31日に僕は5代ウィンチを持って 脳やに行って語りますそこから深テストを実行しようと思っているで11月の中旬に 脳や台の大学院に入る優秀な子 名前は神上さんがキョパラボに 引退しに来ますで大学の 純教授の人がキョパラボで 資料してこいという大理名分の元 彼は確保を持ってきますで彼もサポートします今大事なことは 普通の完成がまだ分かってない以上をなるべく早く検証したい という目的を達出するためにはつつのシンプルな評価ボード でもボードをJLCPCBで発注して 自由が31日までにマニュアをせるこれが今一番大事なタスクになりますそこで通聞君には 評価ボードの設計と発注までの段階を終わらせてほしい評価ボードの要件は 正しく伝訳が来ているか加えて正しく通信ができているか これはツッと評価ボードの配側の確認そしてもう1個は 簡易的に検討しをまいて光方を見るそこを具体的に言うと 新中生のパイプを評価ボードにさせて 光の影とかも同時に見るこれを作って自由が31日到着に合わせて 作成する具体的な評価ボードの内容は 既に先定してくれたステレオ4曲のジャックを使いますあとステレオ4曲が 立たなくしないような工夫もおけますやるなくてもいいことは 実のスリップリングの別独とかスラストベアリングの別独 これに関してはやりません具体的な評価ボードの構成はRP2x4x0 これはウェーブシェアのマイコンを使いますこのピンやファイニューは 任せますごけはどこでもいいですただしデータ通信に関しては TXが0RXが1で接続しますあとネオピクセルを使います これは基盤に両面実装で取り付けますネオピクセルはEGDAで 前回のV1のやつを参考に2mm革のネオピクセル24個を 思っておうらそれぞれにつけます合計48個あと 電源は電圧が24ボルトが ウィンチからくるので24ボルトを出行でこで5ボルトに落とすその回路はEGDAに乗っているので それを使います目的は電圧とデータ通信だけなので 回路工費は以上両面実装で24個をソルトル付けます同時に新宿製のワイヤーを前方向に4本 後方向に4本 合計8本をポーしますこれによって影かどう出るかを見たいその容器がたせできれば それを基盤に起こします最後に大事なことは実際に 常の重さと同じような重さにすることが大事なので表面実装用の納度を合計4個 補儀の4点しかし製法系になるように配置して それを鉄のカラーで重さを調整して固定することができれば 上的です以上

### 新規録音 33.m4a（重量調整の補足）

重さに関してなんですけど、カラーで重量調整するって話があったけど、気分実装のナットに対してネジを通して、そこにカラーを構想にしていって重量調整するのか、それとも大きい思いを、例えば3Dプリントのパーツとかを兵用して、述べていく工夫をするのかというと、どっちが適切なのか。ぶっちゃけなんでもいい。もう、数人くんが、これなら重さいいねっていうのを調整していければOK。ただ、大事なことは、実際につつの重さを見つもっておく必要があって、それを元に最適な思理を選ぶ。だから最初にやることは、実際に怖のつつに搭載される、されうるモジュールを実際に怖の置いておいていって、それを元に、大体のつつの重さを設定して、安全ケースを1.2倍とかかけて、それを、でもの思理にする。他に質問はありますか?RP2R4R0のお金アサインとか通信とかそこの辺で、今後ちょっと質問でてきそうですけど、今の段階で質問できることはないです。OK。RB2R4Rに関しては、既にV1を作っているから、僕に聴けばわかりました。このJVVのバージョンがあるの、気盤から迷いのできるものが多いと思います。ただちょっとゲミツニューと、前の気盤は7枚構成になっているから、若干複雑です。そうですね。なので、好きが見た時にミスをする可能性があるから、実際に大事なことは、TXRXのピンの1歳あっていれば、Nepixelは29番とかに奥だけで良い。というか、シテーサーを1か、もうTXR0RXR1で、ESD帰るものをそこにつける。Nepixelは29番でお願いいします。それ以外の配線は考えなくてもいい。以上。

## クリーンアップ版（整理後）

### メインタスク

**プロジェクト**: 名古屋中部インスタレーション
**期限**: 2025-10-31（現地テスト日）

#### 目的

- ウィンチ46台 + 筒46台の納品
- 現時点: ウィンチはほぼ完成、筒はまだ時間がかかる
- **最優先**: ウィンチが現場でワークするかを早急に検証

#### 現地テスト計画

- **日時**: 2025-10-31
- **持ち込み**: ウィンチ5台
- **場所**: 名古屋
- **目的**: 現地での動作検証

#### サポート体制

- **上條さん**: 名古屋大学院進学予定、2025-11-13にKyopalab研修開始
- **米澤教授**: 上條さんの研修を指示

#### 最優先タスク: 評価ボード設計・発注

**担当**: 鈴木さん
**発注先**: JLCPCB
**到着期限**: 2025-10-24

### 評価ボードの要件

#### 検証項目

1. 正しく電圧が届いているか
2. 正しく通信ができているか（筒と評価ボードの配線確認）
3. 簡易的に検討糸を巻いて光り方を見る（新中製パイプ + 影の確認）

#### ハードウェア構成

**マイコン**: RP2040（WaveShare製）
- TX: GPIO0
- RX: GPIO1
- NeoPixel: GPIO29
- その他のピンアサイン: 自由
- ESD保護回路をTX/RXに追加

**LED**: NeoPixel 2mm角
- 24個 × 両面 = 合計48個
- V1のEGDAデザインを参考

**電源回路**:
- 入力: 24V（ウィンチから）
- 出力: 5V
- EGDAに記載の回路を使用

**コネクタ**: ステレオ4極ジャック
- 揺らぎ防止工夫（任意）

**新中糸ワイヤー**:
- 前方向: 4本
- 後方向: 4本
- 合計: 8本
- 目的: 影の出方確認

**重量調整機構**:
- 表面実装用ナット × 4個（対角4点、対称配置）
- 鉄カラーで重量調整・固定
- 目標: 実際の筒の重量 × 1.2倍（安全係数）

#### スコープ外

- ❌ スリップリングの別途設計
- ❌ スラストベアリングの別途設計

#### 重量調整の方法

**方法1**: ナット+ネジ+カラー
**方法2**: 3Dプリントパーツ+重り

→ **結論**: どちらでもOK。重要なのは実際の筒の重量を見積もり、それに合わせること。

#### 設計の注意点

- V1は7枚構成で複雑
- ミス防止のため、重要なピンのみ固定:
  - TX: GPIO0
  - RX: GPIO1
  - NeoPixel: GPIO29
- ESD保護回路をTX/RXに追加
- それ以外の配線は自由

#### 参考資料

- V1のEGDAファイル（既存）
- kyopanに質問可能（V1を既に作成済み）

## 次のアクション

✅ タスクドキュメント作成: [evaluation-board-design.md](evaluation-board-design.md)
✅ TODO.md更新完了
✅ TODO集約完了

### 次に進めること

1. 筒の重量見積もり（モジュールリスト作成）
2. V1 EGDAファイルの回路抽出
3. 回路設計開始
4. PCBレイアウト設計
5. JLCPCB発注

**担当**: 鈴木さん
**期限**: 2025-10-24（JLCPCB発注締切）

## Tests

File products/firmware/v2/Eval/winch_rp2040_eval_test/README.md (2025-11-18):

# FU Winch v2 - RP2040 Eval Hardware Test

**作成日**: 2025-11-17
**バージョン**: 0.1-test
**MCU**: Waveshare RP2040-Zero
**目的**: winch_rp2040_eval基板のハードウェアユニットテスト

---

## 概要

winch_rp2040_eval基板の各ハードウェアコンポーネントを個別にテストするためのファームウェアです。

**テスト項目:**
1. Onboard LED (NeoPixel GPIO 16)
2. LED PWM (GPIO 14)
3. Electromagnetic Brake / Solenoid (GPIO 26)
4. Stepper Motor (TMC2209 via GPIO 0,1,2,7,8)
5. End Switch / Homing Sensor (GPIO 15)
6. I2C Communication (Slave mode, address 0x08, GPIO 4/5)

---

## ビルド・書き込み手順

### ビルド
```bash
cd "/Users/kyopan/Dropbox (個人)/Obsidian/kyopan/projects/fu/products/firmware/v2/Eval"
pio run -d winch_rp2040_eval_test
```

### 書き込み
```bash
# BOOTSELモード: BOOTSELボタンを押しながらUSB接続
pio run -d winch_rp2040_eval_test -t upload
```

### シリアルモニター起動
```bash
pio device monitor -d winch_rp2040_eval_test
# または
pio device monitor -p /dev/cu.usbmodem* -b 115200
```

---

## シリアルコマンド

### テストコマンド

| コマンド | 動作 | 詳細 |
|---|---|---|
| `1` | Onboard LED テスト | RGB色サイクル（赤→緑→青）5秒間 |
| `2` | LED PWM テスト | 輝度スイープ（0→255→0）5秒間 |
| `3` | 電磁ブレーキテスト | ロック/アンロック切替（1秒間隔）5秒間 |
| `4 <steps>` | ステッパーモーターテスト | 指定ステップ数移動（デフォルト: 1000） |
| `5` | エンドスイッチテスト | センサー値連続表示（任意キーで停止） |
| `6` | I2C通信テスト | スレーブモード受信監視（任意キーで停止） |
| `h` | ヘルプ表示 | コマンド一覧 |
| `i` | TMC2209情報表示 | バージョン、マイクロステップ、電流値 |
| `r` | 全出力リセット | 全LED消灯、モーター停止、ブレーキロック |

---

## テスト手順

### 1. Onboard LED テスト

**コマンド:** `1`

**期待動作:**
- オンボードNeoPixel LEDが以下の順で5秒間点灯
  1. 赤色（約1.7秒）
  2. 緑色（約1.7秒）
  3. 青色（約1.7秒）

**確認項目:**
- [ ] LEDが正しく点灯するか
- [ ] 色が正しく切り替わるか
- [ ] 5秒後に自動消灯するか

---

### 2. LED PWM テスト

**コマンド:** `2`

**期待動作:**
- 外部LED（GPIO 14）の輝度が5秒間で以下のように変化
  1. 消灯 → 最大輝度（2.5秒）
  2. 最大輝度 → 消灯（2.5秒）

**確認項目:**
- [ ] LEDが滑らかに明るくなるか
- [ ] 最大輝度に達するか
- [ ] 滑らかに暗くなるか
- [ ] 5秒後に完全消灯するか

---

### 3. 電磁ブレーキテスト

**コマンド:** `3`

**期待動作:**
- ソレノイド（電磁ブレーキ）が1秒間隔でロック/アンロック切替
- シリアルモニターに状態表示

**確認項目:**
- [ ] アンロック時にソレノイドが動作するか
- [ ] ロック時にソレノイドが停止するか
- [ ] 1秒間隔で正しく切り替わるか
- [ ] 5秒後にロック状態で終了するか

**注意:**
- テスト時間は5秒に制限されています

---

### 4. ステッパーモーターテスト

**コマンド:** `4` または `4 <steps>`

**例:**
```
4          # 1000ステップ移動（デフォルト）
4 500      # 500ステップ移動
4 2000     # 2000ステップ移動
```

**期待動作（⚠️ 重力負荷対応の安全シーケンス）:**
1. TMC2209初期化
2. **モーター有効化（ENABLE先行で保持トルク確保）**
3. 200ms待機（電流安定化）
4. **電磁ブレーキ解除（モーターが既に荷重を保持）**
5. 指定ステップ数だけ移動
6. **電磁ブレーキロック（モーター保持中に先行ロック）**
7. 200ms待機（ブレーキ係合確認）
8. **モーター無効化（ブレーキが既に保持）**

**確認項目:**
- [ ] TMC2209が正常に初期化されるか（`i`コマンドで確認）
- [ ] **モーターENABLE後、自由落下しないか（⚠️ 保持トルク確認）**
- [ ] **ブレーキ解除時、荷重がモーターで保持されているか（⚠️ 最重要）**
- [ ] モーターが指定方向に回転するか
- [ ] 指定ステップ数で正しく停止するか
- [ ] 動作音が正常か（異音・ガタつきがないか）
- [ ] **停止時、ブレーキが先にロックされるか（⚠️ モーター保持中）**
- [ ] **ブレーキロック後、モーター無効化で荷重が移行するか**

**TMC2209設定:**
- RMS電流: 800mA
- マイクロステップ: 16分周
- 最大速度: 1000 steps/s
- 加速度: 500 steps/s²

---

### 5. エンドスイッチテスト

**コマンド:** `5`

**期待動作:**
- センサー状態を100ms間隔で連続表示（デジタル入力）
- LOW (0) = "[TRIGGERED]" 表示（スイッチ押下時）
- HIGH (1) = "[OPEN]" 表示（スイッチ開放時）
- 任意キーで停止

**確認項目:**
- [ ] センサー状態が正しく読み取れるか
- [ ] エンドスイッチ押下時、LOW (0) になるか
- [ ] エンドスイッチ開放時、HIGH (1) になるか
- [ ] 表示が正しく更新されるか

**入力方式:** デジタル入力（`INPUT_PULLUP`）

---

### 6. I2C通信テスト

**コマンド:** `6`

**期待動作:**
- I2Cスレーブモード（アドレス: 0x08）で待機
- ESP32-C6（U1）からのコマンド受信を監視
- 受信データを16進数で表示
- コマンド種別を解析（H=HOMING, M=MOVE, S=STOP）
- 任意キーで停止

**確認項目:**
- [ ] I2Cスレーブとして初期化されるか
- [ ] ESP32-C6からのデータを受信できるか
- [ ] 受信データが正しく表示されるか
- [ ] コマンド解析が正常に動作するか

**I2C設定:**
- スレーブアドレス: 0x08
- SDA: GPIO 4
- SCL: GPIO 5
- クロック: 100kHz（標準モード）

**テスト方法:**
```bash
# RP2040側でテストモード起動
6

# ESP32-C6側から送信（別途U1ファームウェアで実施）
# 'H' コマンド → ホーミング開始
# 'M' + データ → 移動コマンド
# 'S' コマンド → 停止
```

---

## トラブルシューティング

### TMC2209初期化失敗

**症状:** `i`コマンドで "Communication error" 表示

**確認項目:**
1. UART配線確認（GPIO 0: TX, GPIO 1: RX）
2. TMC2209電源供給確認
3. アドレス設定確認（0b00）

**対処:**
```bash
# シリアルモニターで再初期化試行
i
```

---

### ステッパーモーターが動かない

**症状:** `4`コマンド実行後、モーター無反応

**確認項目:**
1. TMC2209初期化確認（`i`コマンド）
2. モーター配線確認
3. 電源電圧確認（24V供給）
4. ENABLE信号確認（GPIO 2）

**対処:**
```bash
# 全リセット後、再テスト
r
i
4 100
```

---

### エンドスイッチ反応しない

**症状:** センサー状態が常に一定（LOW or HIGH固定）

**確認項目:**
1. センサー配線確認（GPIO 15）
2. スイッチタイプ確認（NO: Normally Open / NC: Normally Closed）
3. INPUT_PULLUP設定確認

**対処:**
```bash
# センサー状態連続確認
5
# 手動でスイッチ押下し、LOW (0) ↔ HIGH (1) 変化を確認
# 常にLOW → 配線ショート or NC接点
# 常にHIGH → 配線断線 or NO接点未接続
```

---

## ハードウェア仕様

### ピン配置

```cpp
PIN_ONBOARD_LED   16  // NeoPixel (オンボード)
PIN_LED_PWM       14  // 外部LED PWM制御
PIN_SENSOR        15  // エンドスイッチ（デジタル入力、INPUT_PULLUP）
PIN_SOLENOID      26  // 電磁ブレーキ（PWM出力）
PIN_TMC2209_EN     2  // TMC2209 Enable (LOW=有効)
PIN_TMC2209_TX     0  // UART TX
PIN_TMC2209_RX     1  // UART RX
PIN_TMC2209_STEP   7  // ステップパルス
PIN_TMC2209_DIR    8  // 方向制御
PIN_U2_SDA         4  // I2C SDA
PIN_U2_SCL         5  // I2C SCL

U2_SLAVE_ADDRESS 0x08  // I2Cスレーブアドレス
```

### メモリ使用状況

- **RAM**: 3.9% (10,292 bytes / 262,144 bytes)
- **Flash**: 3.9% (80,888 bytes / 2,093,056 bytes)
- **ファームウェアサイズ**: 約79KB (.uf2)

---

## テストレポート記入例

### テスト実施記録

**実施日時:** YYYY-MM-DD HH:MM
**実施者:** [名前]
**基板番号:** [シリアル番号]

| テスト項目 | 結果 | 備考 |
|---|---|---|
| 1. Onboard LED | ✓ / ✗ | |
| 2. LED PWM | ✓ / ✗ | |
| 3. 電磁ブレーキ | ✓ / ✗ | |
| 4. ステッパーモーター | ✓ / ✗ | |
| 5. エンドスイッチ | ✓ / ✗ | |

**総合評価:** 合格 / 不合格
**不具合内容:**

---

## 参考資料

- [v1 Winch RP2040 Firmware](../../v1/Winch_v1/FU_WINCH_RP2040_U2/)
- [Waveshare RP2040-Zero Datasheet](https://www.waveshare.com/wiki/RP2040-Zero)
- [TMC2209 Datasheet](https://www.trinamic.com/products/integrated-circuits/details/tmc2209-la/)
- [AccelStepper Library](https://www.airspayce.com/mikem/arduino/AccelStepper/)

---

## 変更履歴

| 日付 | 変更内容 | 担当 |
|---|---|---|
| 2025-11-17 | 初版作成 | CIC |

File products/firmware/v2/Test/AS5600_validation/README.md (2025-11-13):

# AS5600 Side-Mount Validation Test

## 目的

スリップリング角度検出用AS5600（AS-S）の側面センシング構成を検証

## 検証内容

### 標準構成 vs 側面構成

**標準構成（軸方向磁化）:**
```
    AS5600センサー
         ↓
    [N | S]  ← ディスク磁石（上から見てNS分割）
    ───┴───
     回転軸
```

**側面構成（今回の検証）:**
```
AS5600センサー →  [磁石]  ← 90°回転配置
                   │
              スリップリング
```

## ハードウェア準備

### 必要な機材
- [x] AS5600評価ボード（手元にあり）
- [x] ESP32-S3開発ボード
- [x] 標準ディスク磁石（6mm径 × 2.5mm厚）
- [ ] ジャンパーワイヤー（4本: VCC, GND, SDA, SCL）
- [ ] ブレッドボード（任意）
- [ ] 定規・ノギス（距離測定用）

### 配線

| AS5600 | ESP32-S3 |
|---|---|
| VCC | 3.3V |
| GND | GND |
| SDA | GPIO8 |
| SCL | GPIO9 |

## PlatformIO セットアップ

### 1. プロジェクトを開く

```bash
cd /Users/kyopan/Dropbox\ \(個人\)/Obsidian/kyopan/projects/fu/products/firmware/v2/Test/AS5600_validation
code .  # VS Code起動
```

### 2. ビルド & アップロード

```bash
# ビルド
pio run

# アップロード
pio run --target upload

# シリアルモニター起動
pio device monitor
```

### 3. VS Code操作

- **ビルド**: `Ctrl+Alt+B` (macOS: `Cmd+Option+B`)
- **アップロード**: `Ctrl+Alt+U` (macOS: `Cmd+Option+U`)
- **シリアルモニター**: `Ctrl+Alt+S` (macOS: `Cmd+Option+S`)

## 実験手順

### 1. 標準構成での動作確認（ベースライン）

1. 磁石をAS5600センサーの真上に配置（標準構成）
2. プログラムを実行
3. 磁石を手動で360°回転
4. 出力結果を記録

**期待される結果:**
```
✓ DETECTED  AGC: 120-140 ✓  Magnitude: 1500-3000
Raw: 0-4095 (線形に変化)
```

### 2. 側面配置での検証（メイン実験）

#### 実験2-1: 距離 0.5mm
1. 磁石を90°回転（側面がセンサーに向く）
2. センサー-磁石間距離: 0.5mm
3. 360°回転テスト
4. 結果記録

#### 実験2-2: 距離 1mm
（同上）

#### 実験2-3: 距離 2mm
（同上）

#### 実験2-4: 距離 3mm
（同上）

### 3. 評価基準

| 項目 | 合格条件 |
|---|---|
| **磁石検出** | `✓ DETECTED` が常に表示 |
| **角度範囲** | Raw値が0-4095を線形にカバー |
| **AGC値** | 96-160の範囲内（最適: 128±32） |
| **Magnitude** | 1000以上（磁場強度十分） |
| **安定性** | 同一角度で値のブレが±10以内 |

## シリアルモニター出力例

```
========================================
AS5600 Validation Test
Side-Mounted Magnet Configuration
========================================

✓ AS5600 detected

Test started - Rotate magnet slowly 360°
----------------------------------------

Raw: 0      Angle: 0.00°    Status: ✓ DETECTED   AGC: 128 ✓  Magnitude: 2048
Raw: 100    Angle: 8.79°    Status: ✓ DETECTED   AGC: 130 ✓  Magnitude: 2055
Raw: 200    Angle: 17.58°   Status: ✓ DETECTED   AGC: 127 ✓  Magnitude: 2040
...
```

## 結果記録テンプレート

### 標準構成（ベースライン）

| 項目 | 結果 |
|---|---|
| 磁石検出 | ✓ / ✗ |
| AGC範囲 | min-max |
| Magnitude | min-max |
| 角度線形性 | 良好 / 不良 |
| 備考 | - |

### 側面配置 - 距離 0.5mm

| 項目 | 結果 |
|---|---|
| 磁石検出 | ✓ / ✗ |
| AGC範囲 | min-max |
| Magnitude | min-max |
| 角度線形性 | 良好 / 不良 |
| 備考 | - |

### 側面配置 - 距離 1mm

| 項目 | 結果 |
|---|---|
| 磁石検出 | ✓ / ✗ |
| AGC範囲 | min-max |
| Magnitude | min-max |
| 角度線形性 | 良好 / 不良 |
| 備考 | - |

### 側面配置 - 距離 2mm

| 項目 | 結果 |
|---|---|
| 磁石検出 | ✓ / ✗ |
| AGC範囲 | min-max |
| Magnitude | min-max |
| 角度線形性 | 良好 / 不良 |
| 備考 | - |

### 側面配置 - 距離 3mm

| 項目 | 結果 |
|---|---|
| 磁石検出 | ✓ / ✗ |
| AGC範囲 | min-max |
| Magnitude | min-max |
| 角度線形性 | 良好 / 不良 |
| 備考 | - |

## トラブルシューティング

### "✗ AS5600 NOT detected"
- I2C配線を確認（SDA/SCL逆接続？）
- AS5600のVCC電圧確認（3.3V供給？）
- I2Cプルアップ抵抗確認（通常2.2kΩ-4.7kΩ）
- `pio device list` でデバイス認識確認

### "✗ NO MAGNET"
- 磁石の向きを確認（NS極の方向）
- センサー-磁石間距離を調整（0.5-3mm）
- 磁石の磁力確認（ネオジム推奨）

### "[TOO WEAK]"
- 磁石をセンサーに近づける
- より強力な磁石に交換（N35 → N52）

### "[TOO STRONG]"
- 磁石をセンサーから離す
- より弱い磁石に交換

### "AGC値が範囲外"
- センサー-磁石間距離を調整
- 磁石の向きを微調整
- AGC < 96: 磁石を近づける
- AGC > 160: 磁石を離す

### シリアルモニターが開かない
```bash
# デバイス確認
pio device list

# 手動でシリアルモニター起動
pio device monitor --baud 115200
```

## 次のステップ

### 検証成功の場合
1. 最適距離を決定（AGC値が最も安定）
2. 径方向磁化リング磁石を発注
3. リング磁石での本格検証
4. tube-v2-circuit-design.mdに結果反映

### 検証失敗の場合
1. 代替案A: 小型ディスク磁石を複数配置
2. 代替案B: より強力な磁石（N52グレード）
3. 代替案C: AS5600の代わりに別のエンコーダー検討

## 関連ドキュメント

- [tube-v2-circuit-design.md](../../specs/v2/architect_v2/tube-v2-circuit-design.md) - V2回路設計仕様
- [AS5600データシート](https://ams.com/documents/20143/36005/AS5600_DS000365_5-00.pdf)
- [AS5600コンポーネント仕様](../../specs/v2/Component/AS5600.md)

## プロジェクト構造

```
AS5600_validation/
├── platformio.ini       # PlatformIO設定
├── src/
│   └── main.cpp        # メインプログラム
└── README.md           # このファイル
```

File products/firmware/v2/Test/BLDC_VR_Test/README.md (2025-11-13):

# FU Tube v2 - Pitch Motor Test Firmware

**作成日**: 2025-11-13
**ボード**: ESP32-S3-MINI-1-N8
**開発環境**: PlatformIO + Arduino Framework

---

## 概要

ESP32-S3とBLDCモーター + 可変抵抗器（50kΩ）を用いたPitchモーターの動作テストファームウェア。

**テスト項目:**
1. 可変抵抗器による角度検出（ADC読取）
2. SimpleFOCによるBLDCモーター制御
3. 速度制御 + 位置フィードバック制御
4. キャリブレーション機能

---

## ハードウェア構成

### ESP32-S3 GPIO割当（#2）

| 機能 | GPIO | 備考 |
|---|---|---|
| **ADC (Pitch角度)** | **GPIO10** | 可変抵抗器角度読取（12bit ADC） |
| **FOC PWM_U (Pitch)** | **GPIO14** | PitchモーターU相 |
| **FOC PWM_V (Pitch)** | **GPIO15** | PitchモーターV相 |
| **FOC PWM_W (Pitch)** | **GPIO16** | PitchモーターW相 |

### 可変抵抗器仕様

| 項目 | 仕様 |
|---|---|
| **型番** | RK0971210-F15-C0-B503 |
| **抵抗値** | 50kΩ ±20% |
| **回転角度** | 300° ±5° |
| **出力電圧** | 0-3.3V（ESP32-S3 ADC入力） |
| **ADC分解能** | 12bit (4096段階) → 約0.073°/LSB |

### BLDCモーター仕様

| 項目 | 仕様 |
|---|---|
| **ポールペア数** | 7 |
| **相抵抗** | 6.5Ω |
| **KV値** | 330 |
| **制御方式** | SimpleFOC（速度制御 + 位置フィードバック） |

---

## セットアップ

### 1. 開発環境

**必須:**
- [PlatformIO IDE](https://platformio.org/install/ide?install=vscode)（VSCode拡張機能）
- または PlatformIO Core（CLI）

### 2. プロジェクトのビルド

```bash
cd /path/to/Test
pio run
```

### 3. ファームウェア書き込み

```bash
# 自動書き込み（USB接続時）
pio run --target upload

# シリアルポート指定
pio run --target upload --upload-port /dev/ttyACM0
```

**書き込み方法:**
1. ESP32-S3をUSB Type-Cケーブルで接続
2. 自動的にダウンロードモードに入る（自動リセット対応）
3. 書き込み完了後、自動的にプログラムが起動

### 4. シリアルモニタ起動

```bash
pio device monitor
```

---

## 使い方

### 起動時の表示

```
========================================
FU Tube v2 - Pitch Motor Test
ESP32-S3 + BLDC + Variable Resistor
========================================

Variable Resistor Sensor initialized
BLDC Driver initialized
Motor initialized with SimpleFOC

========================================
Commands:
  C        - Calibrate variable resistor
  E        - Enable motor
  D        - Disable motor
  T<angle> - Set target angle (e.g., T45)
  S        - Show current status
========================================

ADC:2048 | Volt:1.65V | Angle:150.00° | Target:  0.00° | Motor:OFF
```

### コマンド一覧

| コマンド | 説明 | 例 |
|---|---|-----|
| **C** | キャリブレーション実行 | `C` |
| **E** | モーター有効化 | `E` |
| **D** | モーター無効化 | `D` |
| **T<角度>** | 目標角度設定（0-300°） | `T45`, `T150` |
| **S** | 詳細ステータス表示 | `S` |

### キャリブレーション手順

1. シリアルモニタで`C`コマンド入力
2. Pitch軸を物理的に**0°位置**に移動
3. Enterキーを押す → ADC最小値（`adc_min`）取得
4. Pitch軸を物理的に**300°位置**に移動
5. Enterキーを押す → ADC最大値（`adc_max`）取得
6. キャリブレーション完了

**キャリブレーション例:**
```
========================================
Variable Resistor Calibration
========================================
Rotate the Pitch axis to 0° position
Press ENTER to continue...
<Enterキー入力>
0° position ADC value: 120

Rotate the Pitch axis to 300° position
Press ENTER to continue...
<Enterキー入力>
300° position ADC value: 3950

✓ Calibration completed successfully!
ADC range: 120 - 3950
Resolution: 0.078°/LSB
========================================
```

### モーター制御例

```
# モーター有効化
E
Motor ENABLED

# 目標角度45°に設定
T45
Target angle set to: 45.00 degrees

# 目標角度150°に設定
T150
Target angle set to: 150.00 degrees

# モーター無効化
D
Motor DISABLED
```

### ステータス表示例

```
# Sコマンドで詳細ステータス表示
S

========================================
Current Status
========================================
Variable Resistor:
  ADC Value: 2048 / 4095
  Voltage:   1.650 V
  Angle:     150.00 degrees

Calibration:
  Status:    DONE
  ADC Min:   120 (0°)
  ADC Max:   3950 (300°)
  Range:     3830
  Resolution: 0.078°/LSB

Motor:
  State:     ENABLED
  Target:    150.00 degrees
  Current:   150.12 degrees
  Error:     -0.12 degrees

Motor Parameters:
  Voltage Limit:   1.50 V
  Velocity Limit:  1.30 rad/s
  P Gain:          0.100
  I Gain:          0.300
  D Gain:          0.010
========================================
```

---

## SimpleFOC制御パラメータ

### 速度制御 + 位置フィードバック方式

**制御フロー:**
```
[目標角度] → [位置誤差計算] → [P制御で速度指令] → [速度制限] → [SimpleFOC速度制御] → [モーター駆動]
     ↑                                                                          ↓
     └────────────────────── [可変抵抗器ADC読取] ←─────────────────────────┘
```

### PIDパラメータ

| パラメータ | 値 | 説明 |
|---|-----|---|
| **motor.voltage_limit** | 1.5V | 電圧制限 |
| **motor.PID_velocity.P** | 0.1 | 速度比例ゲイン |
| **motor.PID_velocity.I** | 0.3 | 速度積分ゲイン |
| **motor.PID_velocity.D** | 0.01 | 速度微分ゲイン |
| **motor.LPF_velocity.Tf** | 0.15 | ローパスフィルタ時定数 |
| **motor.velocity_limit** | 1.3 rad/s | 最大速度制限 |
| **motor.PID_velocity.output_ramp** | 150.0 | 出力ランプレート |

### 位置フィードバック制御パラメータ

| パラメータ | 値 | 説明 |
|---|-----|---|
| **VELOCITY_P_GAIN** | 2.5 | 位置誤差→速度変換ゲイン |
| **MAX_VELOCITY** | 1.2 rad/s | 最大速度 |
| **POSITION_DEADBAND** | 0.015 rad | 位置制御デッドバンド（約0.86°） |

---

## トラブルシューティング

### 書き込みエラー

**症状:** `Failed to connect to ESP32`

**対策:**
1. BOOTボタンを押しながらRESETボタンを押す
2. RESETボタンを離す
3. BOOTボタンを離す
4. 再度書き込み実行

### シリアル接続エラー

**症状:** シリアルポートが見つからない

**対策（Linux/macOS）:**
```bash
# デバイス確認
ls /dev/tty*

# ESP32-S3は通常 /dev/ttyACM0 として認識される
```

**対策（macOS）:**
```bash
# ポート権限付与
sudo chmod 666 /dev/ttyACM0
```

### モーターが動かない

**症状:** モーター有効化しても動かない

**チェックリスト:**
1. 電源供給確認（5V）
2. PWMピン配線確認（GPIO14, 15, 16）
3. モータードライバ動作確認
4. シリアルモニタのエラーメッセージ確認

### 角度が安定しない

**症状:** ADC値が不安定に変動

**対策:**
1. 可変抵抗器の配線確認（VCC, GND, OUT）
2. シールド線使用（ノイズ対策）
3. GNDプレーン近接配線
4. デカップリングコンデンサ追加（0.1µF）

---

## 参考資料

- [Variable-Resistor-RK0971210.md](../../specs/v2/Component/Variable-Resistor-RK0971210.md) - 可変抵抗器仕様書
- [ESP32-S3.md](../../specs/v2/Component/ESP32-S3.md) - ESP32-S3仕様書
- [SimpleFOC Documentation](https://docs.simplefoc.com/) - SimpleFOC公式ドキュメント
- [ESP32-S3 Datasheet](https://www.espressif.com/sites/default/files/documentation/esp32-s3_datasheet_en.pdf)

---

## 変更履歴

| 日付 | 変更内容 | 担当 |
|---|---|---|
| 2025-11-13 | 初版作成（ESP32-S3 + BLDC + 可変抵抗器テスト） | CIC |

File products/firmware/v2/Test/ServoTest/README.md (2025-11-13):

# ESP32-S3 Servo Test with Potentiometer + NeoPixel

RCサーボの駆動テストコード（可変抵抗による制御 + ビジュアルフィードバック）

## ハードウェア構成

### 必要な部品
- ESP32-S3 DevKit × 1
- RCサーボ (DS-M005 または互換品) × 1
- 10KΩ可変抵抗器 × 1
- ジャンパー線
- ※ NeoPixel LEDはESP32-S3オンボードRGB LED使用（追加部品不要）

### ピン接続

| コンポーネント | ピン | ESP32-S3 GPIO |
|---|-----|---|
| サーボ信号線 | Signal | GPIO 13 |
| サーボ電源 | VCC | 5V |
| サーボGND | GND | GND |
| 可変抵抗VCC | - | 3.3V |
| 可変抵抗GND | - | GND |
| 可変抵抗信号 | Wiper | GPIO 4 (ADC1_CH3) |
| NeoPixel LED | - | GPIO 48 (onboard) |

### 配線図

```
ESP32-S3 DevKit          RC Servo (DS-M005)
┌─────────────┐          ┌───────┐
│             │          │       │
│   GPIO 13  ─┼─────────▶│ Signal│
│             │          │       │
│     5V     ─┼─────────▶│  VCC  │
│             │          │       │
│    GND     ─┼─────────▶│  GND  │
│             │          └───────┘
│             │
│             │          10K Potentiometer
│             │          ┌───────┐
│    3.3V    ─┼─────────▶│  VCC  │
│             │          │       │
│   GPIO 4   ◀┼──────────│ Wiper │
│             │          │       │
│    GND     ─┼─────────▶│  GND  │
│             │          └───────┘
└─────────────┘
```

## 機能

### 動作概要
1. GPIO 4 (ADC1_CH3) で可変抵抗の電圧を12bit精度で読み取り (0-4095)
2. ADC値をサーボ角度 (0-180°) にマッピング
3. GPIO 13 からPWM信号でサーボを制御
4. オンボードNeoPixel LEDが角度に応じて色変化
   - 0° → 60°: Red → Yellow (赤→黄)
   - 60° → 120°: Yellow → Green (黄→緑)
   - 120° → 180°: Green → Blue (緑→青)
5. 50Hz (20ms間隔) で更新
6. シリアルモニタでADC値と角度をリアルタイム表示

### サーボ仕様
- パルス幅: 500-2500 μs（マイクロ秒精度制御）
- 角度範囲: 0-180°
- 分解能: 2000ステップ（0.5μs精度、従来の11倍）
- 更新レート: 50Hz (20ms間隔)

### ADC仕様
- 分解能: 12bit (0-4095)
- 減衰設定: 11dB (0-3.3V フルレンジ)
- サンプリング: 可変抵抗の位置に応じてリアルタイム
- ノイズフィルタ: 5サンプル移動平均
- デッドバンド: ±2° (ジッター防止)

## ビルド・書き込み

### PlatformIO CLI
```bash
cd /path/to/ServoTest

# ビルド
pio run

# 書き込み
pio run --target upload

# シリアルモニタ
pio device monitor -b 115200
```

### VS Code + PlatformIO拡張機能
1. プロジェクトフォルダを開く
2. PlatformIO: Build (Ctrl+Alt+B)
3. PlatformIO: Upload (Ctrl+Alt+U)
4. PlatformIO: Serial Monitor (Ctrl+Alt+S)

## シリアル出力例

```
=================================
ESP32-S3 Servo + NeoPixel Test
=================================
Pin Configuration:
  Servo Signal: GPIO 13
  Potentiometer: GPIO 4 (ADC1_CH3)
  NeoPixel LED: GPIO 48 (onboard)
=================================

[NeoPixel] Initialized onboard RGB LED
[NeoPixel] Brightness: 50/255
[NeoPixel] Color mapping: 0°=Red → 90°=Green → 180°=Blue
[Filter] Moving average: 5 samples, Deadband: ±2°

[ADC] Initialized 12-bit ADC (0-4095)
[Servo] Attached to GPIO 13
[Servo] Pulse width: 500-2500 us
[Servo] Angle range: 0-180 degrees
[Servo] Initial position: 90 degrees (center)

Setup complete. Starting servo + LED control...

[Update] Filtered Angle:  90° → 1500 μs (change: +90°)
[Update] Filtered Angle:  95° → 1555 μs (change: +5°)
[Update] Filtered Angle: 100° → 1611 μs (change: +5°)
[Update] Filtered Angle: 105° → 1666 μs (change: +5°)
...
```

## トラブルシューティング

### サーボが動かない
- 5V電源の供給を確認
- GPIO 13 の接続を確認
- サーボの動作電圧範囲を確認 (DS-M005: 4.8-6V)

### ADC値が変化しない
- 可変抵抗の配線確認 (VCC: 3.3V, GND: GND, Wiper: GPIO 4)
- 可変抵抗の動作確認 (テスターで抵抗値測定)

### NeoPixel LEDが光らない
- ESP32-S3 DevKitのオンボードLED搭載を確認
- GPIO 48がオンボードLEDに接続されているか確認
- 他のGPIOでNeoPixelを制御している場合、NEOPIXEL_PINを変更

### サーボがジッターする（ジリジリ音）
- **ソフトウェア対策** (実装済み):
  - デッドバンド: `DEADBAND_THRESHOLD = 2` (±2°の変化を無視)
  - 移動平均フィルタ: `FILTER_SAMPLES = 5` (5サンプル平均)
  - さらに改善する場合: `DEADBAND_THRESHOLD` を 3〜5 に増やす
  - 反応速度を犠牲にして滑らかさ優先: `FILTER_SAMPLES` を 8〜10 に増やす
- **ハードウェア対策**:
  - 5V電源に100μF〜470μF電解コンデンサを並列接続
  - 外部5V ACアダプタ使用（最低1A、推奨2A以上）
  - 10回転精密可変抵抗器への交換（より安定した入力）
- **更新レート調整**:
  - `UPDATE_INTERVAL_MS` を 50ms (20Hz) に変更

### シリアル出力が文字化け
- ボーレート 115200 を確認
- USB-CDC設定を確認 (`ARDUINO_USB_CDC_ON_BOOT=1`)

## V1との違い

| 項目 | V1 (Winch_v1/U1) | V2 (ServoTest) |
|---|---|---|
| 目的 | MQTT連携・複雑制御 | サーボ単体テスト |
| 通信 | WiFi + MQTT | なし（ローカル） |
| センサー | I2C複数系統 | ADC (可変抵抗のみ) |
| LED | NeoPixel多数制御 | オンボード1個 (角度視覚化) |
| OTA | 対応 | 非対応 |
| コード規模 | ~500行 | ~230行 (シンプル) |

## 今後の拡張

### Phase 2: WiFi連携
- MQTTでサーボ角度を遠隔制御
- WebSocketでリアルタイム角度送信

### Phase 3: マルチサーボ
- Pitch軸 + YAW軸の2軸制御
- SimpleFOC統合でBLDCモーター制御

### Phase 4: センサー統合
- AS5600エンコーダーでフィードバック制御
- PIDループで正確な位置制御

## ライセンス

MIT License

## 作成者

kyopan / CIC (2025-11-09)

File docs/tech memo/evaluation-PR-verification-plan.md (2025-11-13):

# 評価PR検証計画

**作成日**: 2025-11-03
**到着予定**: 2025-11-06（3日後）
**検証期間**: 11/6-11/10（5日間）
**担当**: kyopan + 鈴木さん

---

## 🎯 検証目的

評価PR基板を使用して、本番PR基板設計に必要な情報を収集し、リスクを早期発見する。

---

## 📋 評価PRの仕様（推定）

### 評価PR vs 本番PR

| 項目 | 評価PR | 本番PR |
|---|---|---|
| **形状** | 円形板 | リング状 |
| **HR連携** | 無し | 有り（±60°回転） |
| **スリップリング** | 無し | 有り |
| **モーター** | 無し | Pitch/YAW BLDC接続 |
| **HR** | 無し | 有り |
| **真鍮線接続** | 有り（12点） | 有り（12点） |
| **マイコン配置** | 考慮なし | 最適化配置 |
| **用途** | 通信・LED・耐久性テスト | 本番展示 |

### 評価PRで検証できること
✅ 真鍮線×12の接続品質
✅ GR/CRとの通信（I2C）
✅ LED制御（NeoPixel）
✅ 電源供給
✅ ウィンチモジュールの耐久性
✅ 筒を被せたLEDの光り方

### 評価PRで検証できないこと
❌ Pitch軸回転機構
❌ スリップリング連続回転
❌ モーター制御
❌ 本番配置での干渉

---

## 🧪 検証項目一覧

### 1. LED光り方確認（優先度: 高）

#### 目的
- 筒を被せた状態でのLED光量・分布確認
- 前面/背面LED配置の視覚的評価
- 中心集中配置 vs 点状配置の比較（10/17会議で検討中）

#### 検証手順
1. **準備**
   - [ ] 評価PR + GR + CR組み立て
   - [ ] 筒（76mm直径）準備
   - [ ] 電源供給（5V）
   - [ ] LED制御ファームウェア書き込み

2. **前面LED確認**
   - [ ] GR前面NeoPixel全点灯（白色）
   - [ ] 筒を被せて光量確認
   - [ ] 光のムラ確認
   - [ ] 写真・動画撮影

3. **背面LED確認**
   - [ ] GR背面NeoPixel全点灯（白色）
   - [ ] 筒を被せて光量確認
   - [ ] 光のムラ確認
   - [ ] 写真・動画撮影

4. **色パターンテスト**
   - [ ] 赤/緑/青/白の単色テスト
   - [ ] グラデーション表示
   - [ ] アニメーションパターン
   - [ ] 視覚効果の記録

5. **比較検討（可能なら）**
   - [ ] 中心集中配置パターンの試作
   - [ ] 点状配置との視覚比較
   - [ ] 菅野さんへの確認

#### 成果物
- LED光り方レポート（写真・動画付き）
- 本番PR設計へのフィードバック

#### 所要時間
- 1日（11/6）

---

### 2. ウィンチモジュール耐久性確認（優先度: 高）

#### 目的
- ウィンチケーブル接続の耐久性確認
- スリップリング無しでの通信安定性
- 長時間動作時の発熱・劣化チェック

#### 検証手順
1. **初期状態確認**
   - [ ] ウィンチケーブル接続確認
   - [ ] 4極ステレオミニプラグ接続品質確認
   - [ ] 電源供給確認（24V → 5V）
   - [ ] 通信確認（UART）

2. **連続動作テスト**
   - [ ] 昇降動作×100回
   - [ ] 停止状態×1時間
   - [ ] 再度昇降動作×100回
   - [ ] 接続部の異常確認

3. **振動テスト**
   - [ ] 昇降中の振動測定
   - [ ] 接続部のゆるみ確認
   - [ ] ケーブル断線の兆候チェック

4. **発熱テスト**
   - [ ] 連続動作1時間
   - [ ] 接続部の温度測定
   - [ ] DCDCの温度測定
   - [ ] マイコンの温度測定

5. **劣化確認**
   - [ ] プラグ接点の状態確認
   - [ ] 配線の劣化確認
   - [ ] 基板の異常確認

#### 成果物
- 耐久性テストレポート
- 改善提案（必要時）

#### 所要時間
- 2日（11/7-11/8）

---

### 3. 通信チェック（優先度: 高）

#### 目的
- ESP32-S3間通信確認
- I2C通信品質確認（Grid-EYE, AS5600, GY-85）
- NeoPixel制御信号確認
- ウィンチ基板との通信確認

#### 検証手順

**3-1. ESP32-S3 #1 ↔ #2通信**
- [ ] UART通信確認（ボーレート、エラーレート）
- [ ] データ送受信テスト
- [ ] 通信遅延測定
- [ ] エラーハンドリング確認

**3-2. I2C通信（SDA0/SCL0系統）**
- [ ] Grid-EYE #1 (GRF) アドレス確認
- [ ] Grid-EYE #2 (GRB) アドレス確認
- [ ] 熱画像データ取得
- [ ] データ更新レート確認
- [ ] エラーレート測定

**3-3. I2C通信（SDA1/SCL1系統）**
- [ ] AS5600（DIR）アドレス確認
- [ ] GY-85 IMUアドレス確認
- [ ] 角度データ取得
- [ ] 加速度・ジャイロデータ取得
- [ ] エラーレート測定

**3-4. NeoPixel制御**
- [ ] W2_3（GRF前面）制御確認
- [ ] W4_5（GRB背面）制御確認
- [ ] W6（CR背面）制御確認
- [ ] 同期制御確認
- [ ] フレームレート測定

**3-5. ウィンチ基板通信**
- [ ] UART接続確認
- [ ] コマンド送受信テスト
- [ ] 昇降制御確認
- [ ] ステータス取得確認

#### 信号品質測定
- [ ] オシロスコープでI2C信号波形確認
- [ ] プルアップ抵抗値確認（内部プルアップ動作）
- [ ] ノイズレベル測定
- [ ] 真鍮線経由の信号劣化確認

#### 成果物
- 通信品質レポート
- オシロスコープ波形データ
- 改善提案（必要時）

#### 所要時間
- 2日（11/9-11/10）

---

### 4. 電源供給確認（優先度: 中）

#### 目的
- 5V電源の安定性確認
- 電流容量確認
- 電圧降下測定

#### 検証手順
1. **電源供給経路確認**
   - [ ] HR → PR → GR/CR の5V供給
   - [ ] 各ポイントの電圧測定
   - [ ] 電圧降下測定

2. **負荷テスト**
   - [ ] LED全点灯時の電流測定
   - [ ] Grid-EYE動作時の電流測定
   - [ ] 全部品同時動作時の電流測定
   - [ ] 電圧安定性確認

3. **DCDC性能確認**
   - [ ] 24V → 5V変換効率
   - [ ] リップルノイズ測定
   - [ ] 発熱測定

#### 成果物
- 電源供給レポート
- 本番PR設計への電流容量フィードバック

#### 所要時間
- 0.5日（11/10午前）

---

### 5. 真鍮線接続品質（優先度: 中）

#### 目的
- 真鍮線×12の接続品質確認
- 半田付け強度確認
- 信号伝送品質確認

#### 検証手順
1. **接続状態確認**
   - [ ] 各真鍮線の導通確認
   - [ ] 半田付け外観確認
   - [ ] 接続部の機械的強度テスト

2. **信号品質確認**
   - [ ] I2C信号（真鍮線経由）の波形確認
   - [ ] NeoPixel信号（真鍮線経由）の波形確認
   - [ ] ノイズレベル測定

3. **振動テスト**
   - [ ] 振動負荷を与えながら通信確認
   - [ ] 断線の兆候チェック

#### 成果物
- 真鍮線接続品質レポート
- 本番PR設計への半田付け方法フィードバック
- 治具設計への要件

#### 所要時間
- 0.5日（11/10午後）

---

## 📅 検証スケジュール

| 日付 | 検証項目 | 担当 | 成果物 |
|---|---|---|---|
| **11/6（水）** | 1. LED光り方確認 | kyopan + 鈴木 | LED光り方レポート |
| **11/7（木）** | 2-1. ウィンチ耐久性（初期） | kyopan | 耐久性テスト途中レポート |
| **11/8（金）** | 2-2. ウィンチ耐久性（完了） | kyopan | 耐久性テスト最終レポート |
| **11/9（土）** | 3-1. 通信チェック（I2C） | kyopan | 通信品質レポート（I2C） |
| **11/10（日）** | 3-2. 通信チェック（NeoPixel）<br/>4. 電源供給<br/>5. 真鍮線接続 | kyopan | 通信品質レポート（NeoPixel）<br/>電源供給レポート<br/>真鍮線接続レポート |

---

## 🎯 検証完了条件

### 必須項目
- [x] LED光り方レポート完成
- [ ] 耐久性テストレポート完成
- [ ] 通信品質レポート完成

### 本番PR設計へのフィードバック
- [ ] LED配置決定（中心集中 or 点状）
- [ ] 真鍮線接続方法確定
- [ ] I2C信号品質確認（問題なし or 対策必要）
- [ ] NeoPixel制御確認（問題なし or 対策必要）
- [ ] 電源容量確認（十分 or 増強必要）

---

## 🛠️ 必要な機材・環境

### 測定機器
- [ ] オシロスコープ（I2C波形確認用）
- [ ] デジタルマルチメータ（電圧・電流測定）
- [ ] 温度計（非接触 or 熱電対）

### 環境
- [ ] 作業台
- [ ] 電源（24V、5V）
- [ ] ウィンチモジュール
- [ ] 筒（76mm直径）
- [ ] PC（ファームウェア書き込み、データ記録）

### ソフトウェア
- [ ] EasyEDAまたはKiCad（回路図参照用）
- [ ] Arduino IDE / PlatformIO（ファームウェア）
- [ ] シリアルモニタ（通信確認用）

---

## 📝 検証で判明した問題の対応フロー

```
問題発見
  ↓
原因分析
  ↓
対応優先度判断
  ├─ 致命的 → 本番PR設計に反映（必須）
  ├─ 重要 → 本番PR設計に反映（推奨）
  └─ 軽微 → 記録・監視（改善検討）
  ↓
改善案検討
  ↓
kyopan + 鈴木さんレビュー
  ↓
本番PR設計仕様更新
```

---

## 🔗 関連ドキュメント

- [PR-board-design-specification.md](PR-board-design-specification.md) - PR基板設計仕様書
- [PR-board-WBS.md](PR-board-WBS.md) - PR基板WBS
- [tube-body-v2-implementation-plan.md](tube-body-v2-implementation-plan.md) - 全体実装計画
- [HR-mechanical-dimensions.md](HR-mechanical-dimensions.md) - HR基板機械寸法ワークシート
- [actuar-wiring-2025-10-23.png](../../notes/actuar-wiring-2025-10-23.png) - 配線図

---

## ✅ レビュー承認

| 役割 | 氏名 | 日付 | 署名 |
|---|---|---|---|
| 検証計画作成 | kyopan | 2025-11-03 | |
| レビュー | 鈴木さん | | |
| 承認 | | | |

---

**作成者**: CIC
**ステータス**: 検証待ち（11/6開始予定）

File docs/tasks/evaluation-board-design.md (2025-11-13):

# 評価ボード設計・発注準備・確認タスク

## 📅 スケジュール

| マイルストーン | 日時 | 詳細 |
|---|---|---|
| **発注完了** | 2025-10-24 | JLCPCB発注締切 |
| **評価ボード到着** | 2025-10-24 | 名古屋現地テスト前日着 |
| **現地テスト** | 2025-10-31 | ウィンチ5台+評価ボード5台 |
| **上條さん研修** | 2025-11-13 (Thu) | Kyopalab弟子入り開始 |

## 🎯 目的

ウィンチが現場でワークするかを検証するための**筒評価ボード**を設計・発注する。

- 筒の完成時期が見積もれていない状況で、なるべく早く検証を実行
- ウィンチとのインターフェース（電源・通信・機械的負荷）を検証
- 1ヶ月程度の耐久テストでケーブル断線リスクを評価

## 📋 プロジェクト背景

| 項目 | 内容 |
|---|---|
| **現状** | ウィンチはほぼ完成、筒はまだ時間がかかる |
| **目標台数** | ウィンチ60台（予備14台）+ 筒60台（予備14台）|
| **現地テスト** | 2025-10-31にウィンチ5台+評価ボード5台を名古屋に持ち込み |
| **サポート体制** | 上條さん（名古屋大学院進学予定）が2025-11-13からKyopalabで研修、2026年4月から筒サポート実施 |

## ✅ 検証項目

| # | 検証内容 | 詳細 | 担当 |
|---|---|---|---|
| 1 | **電圧チェック** | ウィンチから24Vが正しく供給されているか | 鈴木さん |
| 2 | **通信チェック** | データ通信（TX/RX）が正しく動作するか | 鈴木さん |
| 3 | **光り方チェック** | 検討糸（ケント紙固定用）を巻いて影・光の干渉パターンを確認 | 鈴木さん |
| 4 | **ケーブル断線チェック** | 繰り返しウィンチを上下させ、1ヶ月間耐久テストを実施<br>**テストプログラム**: kyopanが作成（双方向通信を定期的に実行し、1ヶ月間ログ記録） | kyopan（プログラム）<br>鈴木さん（実行） |

## 🔧 ハードウェア仕様

### マイコン

| 項目 | 仕様 |
|---|---|
| **型番** | RP2040（WaveShare製） |
| **TX** | GPIO0（固定・ESD保護回路追加） |
| **RX** | GPIO1（固定・ESD保護回路追加） |
| **NeoPixel** | GPIO29（固定） |
| **その他ピン** | 自由 |

### LED

| 項目 | 仕様 |
|---|---|
| **型番** | NeoPixel 2mm角 |
| **数量** | 24個 × 両面 = **合計48個** |
| **配置** | 円環状に両面実装 |
| **参考** | [V1 EasyEDAデザイン](https://pro.easyeda.com/editor#id=91112fbff8f44189b064c06750374ec7) |

### 電源回路

| 項目 | 仕様 |
|---|---|
| **入力電圧** | 24V（ウィンチから供給） |
| **出力電圧** | 5V |
| **出力電流** | 2A |
| **回路** | 24V→5V DCDC降圧回路（EasyEDA V1参照） |

### コネクタ

| 項目 | 仕様 |
| --- | --- |
| **型番** | ステレオ4極ジャック |
| **要件** | **脱落防止対策を施す**（揺らぎ対策） |

### 真鍮製ワイヤー（ケント紙固定・影検証用）

| 項目 | 仕様 |
|---|---|
| **素材** | 真鍮製 Φ1mm |
| **前方向** | 4本 |
| **後方向** | 4本 |
| **合計** | **8本** |
| **目的** | ケント紙前後固定 + 光の干渉パターン・影の検証 |

### 重量調整機構

| 項目 | 仕様 |
|---|---|
| **基本構造** | 表面実装用ナット × 4個（対角4点、対称配置） |
| **調整方法** | 鉄カラーで重量調整・固定 |
| **目標重量** | 実際の筒重量 × **1.2倍**（安全係数） |
| **設計裁量** | 下記2案のいずれか、または独自案 |

#### 重量調整の実装方法（2案）

| 案 | 方法 | 詳細 |
|----|---|---|
| **案1** | ナット+ネジ+カラー | ナットにネジを通し、カラーを複数個重ねて重量調整 |
| **案2** | 3Dプリントパーツ+重り | 3Dプリントパーツで構造を作り、重りを配置 |

**結論**: **どちらでもOK**。重要なのは**実際の筒重量を見積もり、それに合わせること**。

## ❌ スコープ外

以下は評価ボードには含めない：

- スリップリングの別途設計
- スラストベアリングの別途設計

## 📐 設計プロセス

### Step 1: 筒の重量見積もり

| # | タスク | 詳細 |
|---|---|---|
| 1 | モジュールリスト作成 | 筒に搭載される/されうるモジュールを列挙 |
| 2 | 重量測定 | 各モジュールの実測重量を記録 |
| 3 | 合計重量計算 | 全モジュールの合計重量を算出 |
| 4 | 目標重量設定 | 合計重量 × **1.2倍**（安全係数） |

### Step 2: 回路設計

| # | タスク | 詳細 |
|---|---|---|
| 1 | V1回路抽出 | [EasyEDA V1](https://pro.easyeda.com/editor#id=91112fbff8f44189b064c06750374ec7)（7枚構成）から必要回路を抽出 |
| 2 | RP2040配線 | TX=GPIO0, RX=GPIO1, NeoPixel=GPIO29（**固定**）|
| 3 | ESD保護回路 | TX/RXにESD保護回路を追加 |
| 4 | 電源回路 | 24V→5V 2A DCDC降圧回路を配置 |

### Step 3: 基板レイアウト

| # | コンポーネント | 配置要件 |
|---|---|---|
| 1 | NeoPixel 48個 | 円環状、両面24個ずつ |
| 2 | RP2040 | 中央配置 |
| 3 | ステレオ4極ジャック | 脱落防止対策付き |
| 4 | 真鍮製ワイヤーポート | Φ1mm対応、8本（前4本+後4本） |
| 5 | 表面実装用ナット | 4個（対角・対称配置） |

### Step 4: JLCPCB発注

| 項目 | 内容 |
|---|---|
| **発注先** | JLCPCB |
| **到着目標** | **2025-10-24** |
| **数量** | 最低5枚（現地テスト用）+ 予備 |

## 📊 タスク分解

| # | Phase | タスク | 担当 | 期限 | Status |
|---|---|---|---|---|---|
| 1 | 調査 | V1 EasyEDAファイル確認・必要回路抽出 | 鈴木さん | 10/17 | ⚪ Pending |
| 2 | 調査 | 筒の重量見積もり（モジュールリスト作成） | 鈴木さん | 10/17 | ⚪ Pending |
| 3 | 設計 | 回路図作成（EasyEDA） | 鈴木さん | 10/18 | ⚪ Pending |
| 4 | 設計 | PCBレイアウト設計 | 鈴木さん | 10/20 | ⚪ Pending |
| 4-1 | └ | NeoPixel 48個配置（両面24個ずつ） | 鈴木さん | 10/20 | ⚪ Pending |
| 4-2 | └ | RP2040配置・配線 | 鈴木さん | 10/20 | ⚪ Pending |
| 4-3 | └ | 電源回路（24V→5V 2A） | 鈴木さん | 10/20 | ⚪ Pending |
| 4-4 | └ | ステレオ4極ジャック配置 | 鈴木さん | 10/20 | ⚪ Pending |
| 4-5 | └ | ナット4個配置（対角・対称） | 鈴木さん | 10/20 | ⚪ Pending |
| 4-6 | └ | 真鍮製ワイヤーポート8個配置 | 鈴木さん | 10/20 | ⚪ Pending |
| 5 | レビュー | 設計レビュー | kyopan/Hirano | 10/21 | ⚪ Pending |
| 6 | 発注 | Gerberファイル生成 | 鈴木さん | 10/22 | ⚪ Pending |
| 7 | 発注 | **JLCPCB発注** | 鈴木さん | **10/24** | ⚪ Pending |
| 8 | 検証 | 評価ボード到着確認 | 鈴木さん | 10/24 | ⚪ Pending |
| 9 | テスト | ケーブル断線テストプログラム作成 | kyopan | 10/25 | ⚪ Pending |
| 10 | テスト | 名古屋現地テスト | kyopan/鈴木さん | 10/31 | ⚪ Pending |
| 11 | テスト | 1ヶ月耐久テスト開始 | 鈴木さん | 11/01〜 | ⚪ Pending |

## 📝 参考資料

| 資料名 | リンク | 用途 |
| --- | --- | --- |
| **V1 EasyEDAファイル** | [https://pro.easyeda.com/editor#id=91112fbff8f44189b064c06750374ec7](https://pro.easyeda.com/editor#id=91112fbff8f44189b064c06750374ec7) | 回路設計・PCBレイアウトの参考（7枚構成） |
| **RP2040 仕様書** | WaveShare公式 | ピンアサイン確認 |
| **NeoPixel 2mm角データシート** | Adafruit公式 | LED配置・電源仕様 |
| **ステレオ4極ジャック仕様** | 選定後追記 | コネクタ実装仕様 |

## 🔗 関連ドキュメント

| ドキュメント | 用途 |
|---|---|
| [README](../../README.md) | プロジェクト概要 |
| [TODO](../../TODO.md) | プロジェクト全体のTODO |
| [音声文字起こし](../../notes/task-instructions-transcription-2025-10-16.md) | タスク指示の詳細 |

## 📞 質問・レビュー連絡先

| 担当 | 対応内容 |
|---|---|
| **kyopan** | 回路設計、ピンアサイン、V1 EasyEDAファイルの説明 |
| **Hirano** | 設計レビュー、実装アドバイス |
| **上條さん**（2025-11-13〜） | 筒サポート（研修開始後）|

---

## 📌 重要な注意事項

### V1との違い

- **V1**: 7枚構成の複雑な基板
- **評価ボード**: シンプルな1枚基板（必要最小限の機能）

### 固定すべきピンアサイン（変更禁止）

```
TX        → GPIO0  (ESD保護回路付き)
RX        → GPIO1  (ESD保護回路付き)
NeoPixel  → GPIO29
```

### その他のピンは自由に設計してOK

---

## ✅ 完了条件

- [ ] JLCPCB発注完了（2025-10-24まで）
- [ ] 評価ボード5枚以上が10/24に到着
- [ ] 筒の目標重量（×1.2倍）を反映した重量調整機構
- [ ] 全検証項目（電圧・通信・光・耐久）が実行可能な構成

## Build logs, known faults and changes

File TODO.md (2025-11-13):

# Nagoya Tube Installation TODO

## In Progress

- [~] 評価ボード設計・発注（JLCPCB）
  - Started: 2025-10-16
  - Deadline: 2025-10-24（JLCPCB発注締切）
  - Assigned: 鈴木さん
  - Priority: 最優先
  - Details: ウィンチ検証用評価ボード（RP2040 + NeoPixel 48個 + 24V→5V 2A電源回路）
  - Document: [evaluation-board-design.md](docs/tasks/evaluation-board-design.md)

## Pending

- [ ] Winch回路設計V2
  - Priority: High
  - Assigned: kyopan
  - Estimated: 2-3週間
  - Details: V1をベースに改良、モーター制御最適化、通信安定性向上
  - Document: [winch-circuit-design.md](docs/specs/winch-circuit-design.md)
  - Tasks:
    - [ ] V1回路の分析・課題抽出
    - [ ] モーター種別決定（ステッピング vs DC）
    - [ ] 回路図作成（EasyEDA/KiCad）
    - [ ] PCBレイアウト設計
    - [ ] プロトタイプ製作・テスト

- [ ] 筒の重量見積もり
  - Priority: High
  - Estimated: 2h
  - Details: 搭載モジュールをリストアップし、合計重量×1.2倍を算出
  - Blocking: 評価ボードの重量調整機構設計

- [ ] V1 EGDAファイルの回路抽出
  - Priority: High
  - Estimated: 3h
  - Details: 既存V1（7枚構成）から必要な回路（電源、RP2040、NeoPixel）を抽出
  - Blocking: 評価ボード回路設計

- [ ] ケーブル断線テストプログラム作成
  - Priority: High
  - Estimated: 4h
  - Assigned: kyopan
  - Deadline: 2025-10-25
  - Details: 双方向通信を定期的に実行し、1ヶ月間ログ記録するテストプログラム作成

- [ ] 名古屋現地テスト準備（10/31）
  - Priority: Medium
  - Assigned: kyopan, 鈴木さん
  - Details: ウィンチ5台 + 評価ボード5台を持ち込み、動作検証

- [ ] 上條さん研修準備（2025-11-13）
  - Priority: Low
  - Details: 名古屋大学院進学予定・上條さんのKyopalab研修サポート準備（2026年4月から筒サポート本格化）

## Completed

- [x] プロジェクト初期化
  - Completed: 2025-10-13
  - Details: README作成、ディレクトリ構造整備

- [x] 音声タスク指示の文字起こし
  - Completed: 2025-10-16
  - Details: 新規録音32.m4a、33.m4aをWhisperで文字起こし→タスクドキュメント化

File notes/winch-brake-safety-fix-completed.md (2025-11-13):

# 電磁ブレーキ回路の安全性修正完了報告

**修正日**: 2025-10-17
**重要度**: 🔴 Critical（安全性に関わる）
**ステータス**: ✅ 修正完了

---

## 📋 問題の概要

**発見された問題**:
電源投入直後、ESP32S3がまだ起動していない間、SOLENOID端子がハイインピーダンス（Hi-Z）状態になり、Q2のベースがフローティング。ノイズで誤動作し、ブレーキが解除される危険性があった。

**リスク**:
- ウィンチモーターが制御不能で回転
- 負荷（筒）の落下リスク
- 人身事故の可能性

---

## ✅ 実施した修正

### ハードウェア修正

**追加部品**: R6 = 100kΩ プルダウン抵抗

**接続**: Q2ベース - GND間

**回路変更**:
```
修正前:
SOLENOID ─── R8 (10kΩ) ─── Q2 Base
                             |
                            (フローティング) ← 危険

修正後:
SOLENOID ─── R8 (10kΩ) ─── Q2 Base
                             |
                            R6 (100kΩ) ← 追加
                             |
                            GND
```

---

### 修正後の回路図

**オリジナル回路**: [winch-electric-magnetic-brake-original.png](winch-electric-magnetic-brake-original.png)

**修正後の回路**: [winch-electric-magnetic-brake-fixed.png](winch-electric-magnetic-brake-fixed.png)

---

## 🔍 修正後の動作検証

### SOLENOID = Hi-Z（電源投入直後）

```
R8 (10kΩ) と R6 (100kΩ) の分圧
    ↓
Q2ベース ≈ 0V（GNDにプルダウン）
    ↓
Q2 OFF
    ↓
Q1 ON（R7/R9分圧でゲート電圧あり）
    ↓
S_DRN = GND
    ↓
✅ ブレーキ作動（安全）
```

**結果**: 電源投入時、ESP32S3起動前でも**確実にブレーキが作動**

---

### SOLENOID = LOW（明示的なブレーキ作動）

```
0V ─── R8 ─── Q2 Base
                |
               R6
                |
               GND
    ↓
Q2 OFF
    ↓
Q1 ON
    ↓
S_DRN = GND
    ↓
✅ ブレーキ作動
```

---

### SOLENOID = HIGH（ブレーキ解除）

```
3.3V ─── R8 (10kΩ) ─── Q2 Base
                         |
                        R6 (100kΩ)
                         |
                        GND

Q2ベース電圧 = 3.3V × R6 / (R8 + R6)
             = 3.3V × 100kΩ / 110kΩ
             = 3.0V （Q2のVbe=0.6Vを超える）
    ↓
Q2 ON
    ↓
Q1 OFF
    ↓
S_DRN = 24V
    ↓
✅ ブレーキ解除
```

---

## 🧪 実施すべきテスト

### テスト1: 電源投入時の安全性確認

**手順**:
1. ウィンチモーターに負荷をかける（筒を吊るす）
2. 24V電源を投入
3. ESP32S3起動完了まで観察（数秒）

**期待結果**:
- [ ] ブレーキが作動したまま（モーターが固定）
- [ ] モーターが回転しない
- [ ] 負荷が落下しない

---

### テスト2: ブレーキ制御の動作確認

**手順**:
1. ESP32S3起動完了後、シリアルモニターで確認
2. `digitalWrite(SOLENOID_PIN, HIGH)` でブレーキ解除
3. ブレーキ解除音を確認
4. `digitalWrite(SOLENOID_PIN, LOW)` でブレーキ作動
5. ブレーキ作動音を確認

**期待結果**:
- [ ] HIGHでブレーキ解除
- [ ] LOWでブレーキ作動
- [ ] モーター制御が正常

---

### テスト3: 電源断時の安全性確認（フェイルセーフ）

**手順**:
1. モーターを回転させる（ブレーキ解除状態）
2. 24V電源を突然切断
3. モーター停止を確認

**期待結果**:
- [ ] 電源断後、即座にブレーキ作動
- [ ] モーターが固定される
- [ ] 負荷が落下しない

---

### テスト4: ESP32S3リセット時の安全性確認

**手順**:
1. モーターを回転させる（ブレーキ解除状態）
2. ESP32S3のリセットボタンを押す
3. モーター停止を確認

**期待結果**:
- [ ] リセット後、即座にブレーキ作動
- [ ] モーターが固定される
- [ ] 負荷が落下しない

---

## 📊 修正の効果

| シナリオ | 修正前 | 修正後 |
|---|---|---|
| **電源投入直後** | ❌ 不定（危険） | ✅ ブレーキ作動（安全） |
| **ESP32S3起動中** | ❌ 不定（危険） | ✅ ブレーキ作動（安全） |
| **SOLENOID = LOW** | ✅ ブレーキ作動 | ✅ ブレーキ作動 |
| **SOLENOID = HIGH** | ✅ ブレーキ解除 | ✅ ブレーキ解除 |
| **電源断** | ✅ ブレーキ作動 | ✅ ブレーキ作動 |

**安全性向上**: 電源投入時とESP32S3起動中のリスクを**完全に排除**

---

## 🔗 関連ドキュメント

| ドキュメント | 用途 |
|---|---|
| [winch-electromagnetic-brake-circuit.md](../docs/specs/winch-electromagnetic-brake-circuit.md) | 元の回路仕様 |
| [winch-electromagnetic-brake-circuit-fix.md](../docs/specs/winch-electromagnetic-brake-circuit-fix.md) | 修正案の詳細 |
| [winch-electric-magnetic-brake-original.png](winch-electric-magnetic-brake-original.png) | 修正前の回路図 |
| [winch-electric-magnetic-brake-fixed.png](winch-electric-magnetic-brake-fixed.png) | 修正後の回路図 |

---

## ✅ 完了チェックリスト

### ハードウェア修正

- [x] R6 (100kΩ) を調達
- [x] 基板上のQ2ベース接続点を特定
- [x] R6をQ2ベース-GND間に追加
- [x] 回路図を更新
- [ ] 導通確認（Q2ベース-GND間が100kΩ）

### テスト（実施待ち）

- [ ] テスト1: 電源投入時の安全性確認
- [ ] テスト2: ブレーキ制御の動作確認
- [ ] テスト3: 電源断時の安全性確認
- [ ] テスト4: ESP32S3リセット時の安全性確認

### ドキュメント

- [x] 修正完了報告書作成（このドキュメント）
- [x] 修正後の回路図保存
- [ ] テスト結果記録（テスト完了後）

---

## 🎯 次のアクション

1. **導通確認** - テスターでQ2ベース-GND間が100kΩであることを確認
2. **テスト実施** - 上記4つのテストを実施
3. **テスト結果記録** - このドキュメントに結果を追記
4. **基板発注** - テスト完了後、基板発注準備

---

**この修正により、Winchシステムの安全性が大幅に向上しました。電源投入時やESP32S3起動中でも、確実にブレーキが作動し、モーターが制御不能で回転するリスクが排除されました。**

**修正実施者**: kyopan
**修正確認日**: 2025-10-17

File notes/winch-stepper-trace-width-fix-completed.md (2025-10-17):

# Winch ステッパーモーター トレース幅修正完了レポート

**日付**: 2025-10-17
**担当**: suzukishohei (WPCBB)
**確認**: kyopan

## 📋 概要

ステッパーモーター電源ラインのトレース幅不足問題に対し、迅速な修正が完了しました。

## 🔧 修正内容

### Before (修正前)
- **トレース幅**: 10 mil (0.254 mm)
- **許容電流**: 約 0.5A (1oz銅箔、温度上昇10°C)
- **モーター定格**: 2.0A/相
- **過負荷率**: 400% (危険)

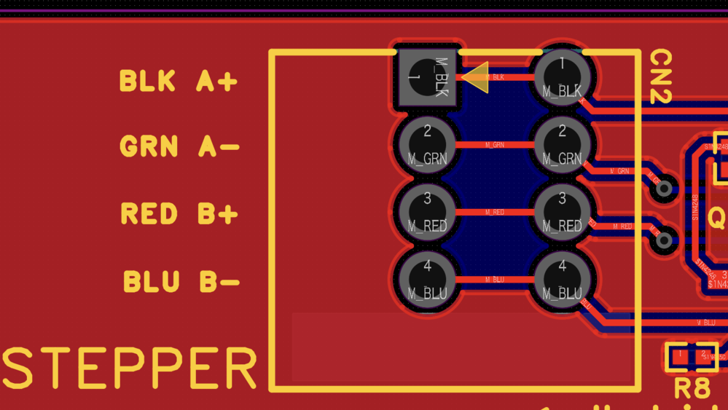
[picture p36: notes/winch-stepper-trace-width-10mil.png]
修正前


### After (修正後)
- **トレース幅**: 40 mil (1.016 mm)
- **許容電流**: 約 1.5A (1oz銅箔、温度上昇20°C)
- **モーター定格**: 2.0A/相
- **安全マージン**: 75% (改善)

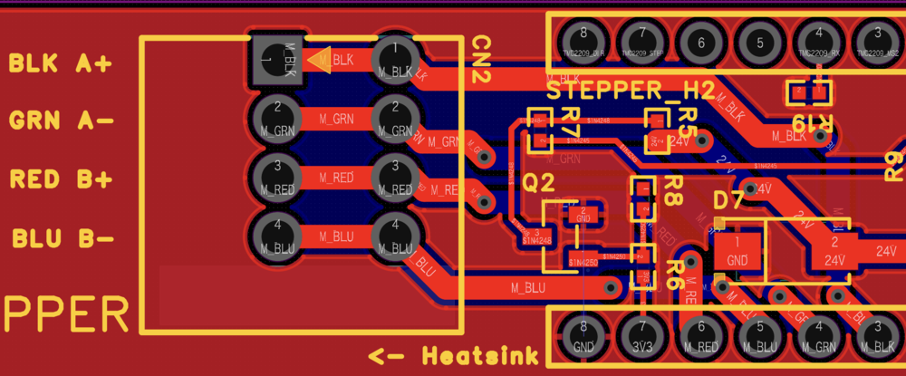
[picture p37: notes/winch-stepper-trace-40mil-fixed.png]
修正後


## 📊 技術評価

### IPC-2221標準による計算

| トレース幅 | 銅箔厚 | 許容電流 (10°C上昇) | 許容電流 (20°C上昇) | 評価 |
|---|---|---|---|---|
| 10 mil | 1oz | 0.5A | 0.7A | ❌ 不足 |
| 40 mil | 1oz | 1.2A | 1.5A | ✅ 実用可 |
| 50 mil | 1oz | 1.5A | 1.8A | ✅ 推奨 |
| 40 mil | 2oz | 2.0A | 2.5A | ✅ 理想 |

### 修正後の評価

**結論**: 40milへの変更により、実用上問題ないレベルに改善

**利点**:
- 過熱リスク大幅低減
- 電圧降下改善（モータートルク向上）
- 長期信頼性向上

**さらなる改善オプション**:
1. **50milへの拡幅**: トレース幅をさらに10mil増やすことで、2.0A定格に対して余裕あり
2. **2oz銅箔の採用**: 40milのまま約2.5A対応可能（発注時に指定）

## 🎯 対象トレース

修正されたトレース:
- **BLK A+** (黒): ステッパーA相プラス
- **GRN A-** (緑): ステッパーA相マイナス
- **RED B+** (赤): ステッパーB相プラス
- **BLU B-** (青): ステッパーB相マイナス

## ✅ 確認事項

- [x] 4本すべてのステッパー電源ラインが40milに変更されている
- [x] コネクタ周辺のトレース配線も太くなっている
- [x] ヒートシンク領域（← Heatsink表記）との干渉がない
- [x] 他の信号線（CN2, Q2周辺）への影響がない

## 📅 タイムライン

| 時刻 | イベント |
|---|---|
| 13:05 | kyopanが問題を発見・解析レポート作成 |
| 13:06 | GitHubにプッシュ |
| 13:06 | Slack fragmented_unityチャンネルに投稿 (@suzukishohei) |
| 13:12 | suzukishoheiが「対応致します」と返信 |
| 13:13 | suzukishoheiが「対応完了です。10 mil → 40 mil」と報告 |
| 13:18 | kyopanが修正を確認・評価 |

**対応時間**: 約8分（発見から修正完了まで）

## 🙏 謝辞

迅速な対応により、基板発注前に重大な設計問題を修正できました。

## 🔗 関連ドキュメント

- [初回解析レポート](winch-stepper-trace-width-analysis.md)
- [Slackスレッド](https://kyopalab.slack.com/archives/C0806K7E9RD/p1760673927643949)
- [電磁ブレーキ回路仕様](../docs/specs/winch-electromagnetic-brake-circuit.md)
- [Winch Circuit Design V2](../docs/specs/winch-circuit-design-v2.md)

## 📝 メモ

### モーター仕様（再掲）
- **型番**: Nema 17 - 17HS24-2004D-B070
- **定格電流**: 2.0A/相
- **電圧**: 24V
- **トルク**: 0.72Nm (101.96oz.in)
- **特徴**: 電磁ブレーキ付き

### 参考: IPC-2221計算式

```
I = k × ΔT^0.44 × A^0.725

I: 電流 (A)
ΔT: 温度上昇 (°C)
A: 断面積 (mil²) = 幅(mil) × 厚さ(mil)
k: 係数 (外層: 0.048, 内層: 0.024)

1oz銅箔 = 1.4 mil厚

40 mil × 1.4 mil = 56 mil²
→ 許容電流 約1.5A (ΔT=20°C)
```

---

**ステータス**: ✅ 修正完了・確認済み

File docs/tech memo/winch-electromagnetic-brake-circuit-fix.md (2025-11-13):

# 電磁ブレーキ回路の安全性問題と修正案

**問題報告日**: 2025-10-17
**重要度**: 🔴 Critical（安全性に関わる）
**プロジェクト**: FU@ComoNe Winch

---

## ⚠️ 問題の概要

**現在の回路の危険性**:
電源投入直後、ESP32S3がまだ起動していない間、SOLENOID端子がハイインピーダンス（Hi-Z）状態になる。この時、Q2のベースがフローティングとなり、ノイズで誤動作する可能性がある。最悪の場合、ブレーキが解除され、**ウィンチモーターが制御不能で回転する危険性**。

---

## 🔍 現在の回路の問題点

### 電源投入シーケンスの解析

```
1. 24V電源投入
    ↓
2. ESP32S3起動開始（数百ms）
    ↓
3. SOLENOID端子 = Hi-Z（GPIO未初期化）
    ↓
4. R8 (10kΩ) でQ2ベースがフローティング
    ↓
5. Q2の状態が不定
    ├─ケースA: Q2 OFF → Q1 ON → ブレーキ作動（OK）
    └─ケースB: Q2 ON → Q1 OFF → ブレーキ解除（危険！）
```

### 問題のメカニズム

**Q2ベースにプルダウン抵抗がない**:
- SOLENOID = Hi-Z の時、ベース電圧が不定
- 電源ノイズや静電気で容易に0.6V以上になる
- Q2が誤ってONになる可能性

**ブレーキ解除の危険性**:
- ウィンチモーターは常に回転方向に力がかかっている
- ブレーキ解除 = 制御不能な回転
- 負荷（筒）の落下リスク

---

## ✅ 修正案

### 修正案1: Q2ベースにプルダウン抵抗追加（推奨）

#### 回路変更

```
修正前:
SOLENOID ─── R8 (10kΩ) ─── Q2 Base
                             |
                            (フローティング)

修正後:
SOLENOID ─── R8 (10kΩ) ─── Q2 Base
                             |
                            R10 (100kΩ)
                             |
                            GND
```

**追加部品**:
- R10: 100kΩ プルダウン抵抗（Q2ベース → GND）

---

#### 動作解析

**SOLENOID = Hi-Z（電源投入直後）**:
```
R8 (10kΩ) と R10 (100kΩ) の分圧
    ↓
Q2ベース ≈ 0V（GNDにプルダウン）
    ↓
Q2 OFF
    ↓
Q1 ON（R6/R7分圧でゲート電圧あり）
    ↓
S_DRN = GND
    ↓
✅ ブレーキ作動（安全）
```

**SOLENOID = LOW（明示的なLOW）**:
```
0V ─── R8 ─── Q2 Base
                |
               R10
                |
               GND
    ↓
Q2 OFF（同上）
    ↓
✅ ブレーキ作動
```

**SOLENOID = HIGH（3.3V）**:
```
3.3V ─── R8 (10kΩ) ─── Q2 Base
                         |
                        R10 (100kΩ)
                         |
                        GND

Q2ベース電圧 = 3.3V × R10 / (R8 + R10)
             = 3.3V × 100kΩ / 110kΩ
             = 3.0V （Q2のVbe=0.6Vを超える）
    ↓
Q2 ON
    ↓
Q1 OFF
    ↓
✅ ブレーキ解除
```

**結論**: R10追加でHi-Z時にQ2が確実にOFFになり、ブレーキが作動する。

---

### 修正案2: ESP32S3のGPIO初期化を最優先（ソフトウェア対策）

#### ファームウェア修正

```cpp
void setup() {
  // ❌ 既存コード（危険）
  // Serial.begin(115200);
  // Wire.begin(8, 9);
  // ... 他の初期化 ...
  // pinMode(SOLENOID_PIN, OUTPUT);
  // digitalWrite(SOLENOID_PIN, LOW);

  // ✅ 修正後（安全）
  // 最優先: ブレーキ制御GPIO初期化
  pinMode(SOLENOID_PIN, OUTPUT);
  digitalWrite(SOLENOID_PIN, LOW);  // ブレーキ作動を明示

  // その後、他の初期化
  Serial.begin(115200);
  Wire.begin(8, 9);
  // ...
}
```

**効果**: 起動から数十ms程度でブレーキ作動を保証

**限界**:
- 完全には起動時間をゼロにできない
- ESP32S3のブートローダーが走る間（数百ms）は依然としてHi-Z
- ハードウェア対策と併用すべき

---

### 修正案3: 外部プルダウン回路（最も確実）

#### ハードウェアプルダウン追加

ESP32S3のGPIOピンに外部プルダウン抵抗を追加:

```
ESP32S3 GPIO (SOLENOID)
    |
    ├─── R11 (10kΩ) ─── GND  ← 追加
    |
    └─── R8 (10kΩ) ─── Q2 Base
                         |
                        R10 (100kΩ)
                         |
                        GND
```

**追加部品**:
- R11: 10kΩ プルダウン抵抗（ESP32S3 GPIO → GND）

**動作**:
- SOLENOID = Hi-Z の時、R11でGNDにプルダウン
- 確実にLOW状態を保証
- ESP32S3起動前から安全

---

## 📊 修正案の比較

| 修正案 | 部品追加 | 安全性 | 実装難易度 | 推奨度 |
|---|---|---|---|---|
| **修正案1: Q2ベースプルダウン** | R10 (100kΩ) × 1 | ⭐⭐⭐⭐⭐ | 低 | ⭐⭐⭐⭐⭐ |
| 修正案2: ファームウェア最適化 | なし | ⭐⭐⭐ | 低 | ⭐⭐⭐ |
| 修正案3: GPIO外部プルダウン | R11 (10kΩ) × 1 | ⭐⭐⭐⭐⭐ | 中 | ⭐⭐⭐⭐ |
| **推奨組み合わせ** | **修正案1 + 修正案2** | **⭐⭐⭐⭐⭐** | **低** | **⭐⭐⭐⭐⭐** |

---

## 🎯 推奨修正（修正案1 + 修正案2）

### ハードウェア修正

**変更内容**:
- Q2ベースとGND間に100kΩプルダウン抵抗（R10）を追加

**回路図**:
```
              3V3
               |
SOLENOID ─┬─ R8 (10kΩ) ─┬─ Q2 Base
          |              |
         (Hi-Z)        R10 (100kΩ)  ← 追加
                         |
                        GND
```

---

### ファームウェア修正

```cpp
// main.cpp

#define SOLENOID_PIN 10  // GPIO番号は要確定

void setup() {
  // ========================================
  // 最優先: ブレーキ制御GPIO初期化
  // ========================================
  pinMode(SOLENOID_PIN, OUTPUT);
  digitalWrite(SOLENOID_PIN, LOW);  // ブレーキ作動（安全）

  Serial.println("Brake engaged (safe)");

  // ========================================
  // その後、他の初期化
  // ========================================
  Serial.begin(115200);
  Serial.println("ESP32S3 U1 Firmware v9");

  // NeoPixel初期化
  onboardLED.begin();
  onboardLED.setPixelColor(0, 255, 0, 0);  // 赤色: 起動中
  onboardLED.show();

  // I2C初期化
  Wire.begin(8, 9);

  // UART初期化
  Serial1.begin(38400, SERIAL_8N1, 17, 18);

  // WiFi初期化
  WiFi.setSleep(false);
  connectWiFi();

  // MQTT接続
  connectMQTT();

  // 初期化完了
  Serial.println("Initialization complete");
}
```

---

## 🧪 修正後のテスト

### テスト1: 電源投入時の安全性確認

**手順**:
1. ウィンチモーターに負荷をかける（筒を吊るす）
2. 24V電源を投入
3. ESP32S3起動完了まで観察（数秒）

**合格基準**:
- [ ] ブレーキが作動したまま（モーターが固定）
- [ ] モーターが回転しない
- [ ] 負荷が落下しない

---

### テスト2: ブレーキ制御の動作確認

**手順**:
1. ESP32S3起動完了後、シリアルモニターで確認
2. `SOLENOID = HIGH` を送信
3. ブレーキ解除音を確認
4. `SOLENOID = LOW` を送信
5. ブレーキ作動音を確認

**合格基準**:
- [ ] HIGHでブレーキ解除
- [ ] LOWでブレーキ作動
- [ ] モーター制御が正常

---

### テスト3: 電源断時の安全性確認

**手順**:
1. モーターを回転させる（ブレーキ解除状態）
2. 24V電源を突然切断
3. モーター停止を確認

**合格基準**:
- [ ] 電源断後、即座にブレーキ作動
- [ ] モーターが固定される
- [ ] 負荷が落下しない

---

## 📝 修正実装チェックリスト

### ハードウェア修正

- [ ] R10 (100kΩ) を調達
- [ ] 基板上のQ2ベース接続点を特定
- [ ] R10をQ2ベース-GND間にハンダ付け
- [ ] 導通確認（Q2ベース-GND間が100kΩ）

### ファームウェア修正

- [ ] `main.cpp`のsetup()を修正
- [ ] SOLENOID_PIN定義を追加
- [ ] GPIO初期化を最優先に配置
- [ ] ビルド・書き込み
- [ ] シリアルモニターで起動ログ確認

### テスト

- [ ] テスト1: 電源投入時の安全性確認
- [ ] テスト2: ブレーキ制御の動作確認
- [ ] テスト3: 電源断時の安全性確認

### ドキュメント更新

- [ ] 回路図に修正を反映
- [ ] `winch-electromagnetic-brake-circuit.md`を更新
- [ ] テスト結果を記録

---

## 🔗 関連ドキュメント

| ドキュメント | 用途 |
|---|---|
| [winch-electromagnetic-brake-circuit.md](winch-electromagnetic-brake-circuit.md) | 元の回路仕様 |
| [winch-circuit-design.md](winch-circuit-design.md) | Winch V2全体設計 |
| [U1_FIRMWARE_OVERVIEW.md](../../firmware/Winch/U1/U1_FIRMWARE_OVERVIEW.md) | U1ファームウェア |

---

## ⚠️ 重要な注意

**この修正は安全性に直結する重要な変更です。**

- 修正なしで運用すると、電源投入時にウィンチが制御不能で回転する危険性
- 負荷（筒）の落下リスク
- 人身事故の可能性

**修正を最優先で実施してください。**

---

**修正担当**: kyopan
**修正期限**: 基板発注前（2025-10-24）
**優先度**: 🔴 最優先（安全性）

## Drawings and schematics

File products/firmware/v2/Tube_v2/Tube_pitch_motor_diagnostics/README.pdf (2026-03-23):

# Tube Pitch Motor Diagnostics 起動ガイド

目的

筒v2のUnit2のマイコンにUSB Cを接続し、水平キャリブレーションを行い、EEPROMに保存 するプログラム。

本ツール（ pitch_diag.py ）を利用するための初期設定と起動方法について説明します。

## 1. パッケージの導入

本ツールはPythonを利用しています。以下のコマンドをターミナル（またはコマンドプロンプ ト）で実行し、必要なパッケージをインストールしてください。

※環境によっては pip3 install PyQt6 pyserial と入力してください。

## 2. 起動方法

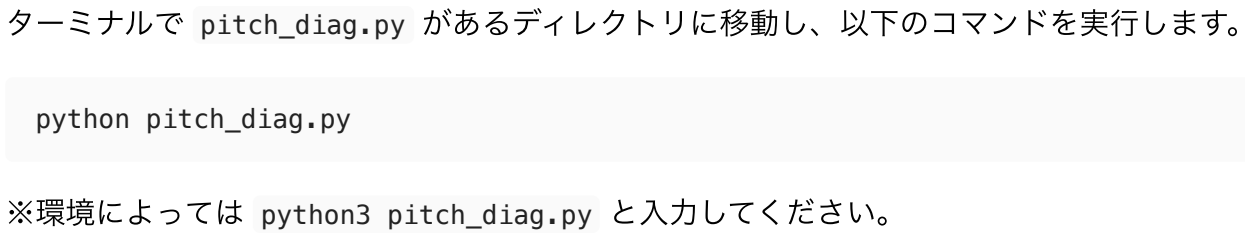
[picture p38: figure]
ターミナルで pitch_diag.py があるディレクトリに移動し、以下のコマンドを実行します。; ※環境によっては python3 pitch_diag.py と入力してください。; python pitch_diag.py

## 3. キャリブレーションの実行方法

GUI起動後、以下の手順でキャリブレーションを行います。

※Winchケーブルが繋がっていなくてもUSB電源のみで動作する

1. GUIを起動する
2. 筒v2のUnit2にUSB Cを挿して片方をPCに接続する（USB CケーブルがLEDリングや真鍮棒 に引っかからないように工夫する）
3. 自動認識されるはずだが、されない場合は左上のメニューから /cu/usbmodem.xxx を選ん でConnectボタンを押す
4. 筒を水平に保ち、青いボタン Calibrate (Horizon) を押す
5. キャリブレーション完了
6. 確認のためPitch Controlスライダー左右に動かすとPitchモーターが回転する

## 4. 導入・実行フロー図

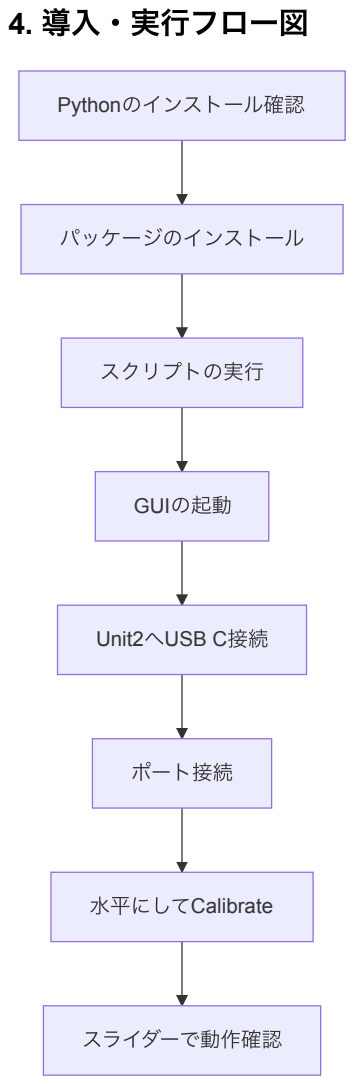
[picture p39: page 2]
Pythonのインストール確認; パッケージのインストール; スクリプトの実行; GUIの起動; Unit2へUSB C接続; ポート接続; 水平にしてCalibrate; スライダーで動作確認

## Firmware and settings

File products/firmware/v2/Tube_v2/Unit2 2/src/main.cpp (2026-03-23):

/* ============================================================================
 *  ______     __         __  __     _ __    ___
 * /_  __/_ __/ /  ___   / / / /__  (_) /_  |_  |
 *  / / / // / _ \/ -_) / /_/ / _ \/ / __/ / __/
 * /_/  \_,_/_.__/\__/  \____/_//_/_/\__/ /____/
 *
 *  FU Product Tube Unit 2 (Motor Master) - Dual Core Edition
 * ============================================================================
 * Core 1 (Arduino Loop): Pitch Control, Comm, State Management
 * Core 0 (Yaw Task): Yaw Motor Control (High Frequency FOC Loop)
 * ============================================================================
 */

#include "YawController.h"
#include <Arduino.h>
#include <Preferences.h>
#include <SimpleFOC.h>
#include <Update.h>
#include <WiFi.h>
#include <Wire.h>

#ifdef FIRMWARE_VERSION
#undef FIRMWARE_VERSION
#endif
#define FIRMWARE_VERSION "2.2.88"

/*
 * v2.2.84 Changelog:
 * - Reliability: Set Serial Timeout to 5ms (was 1000ms) to prevent blocking on
 * noise.
 * - Reliability (Limit): Added strict clamping (-60~60) to avoid "Runaway 90"
 * risk.
 * - Reliability (Init): Added I2C Timeout (1000ms) to prevent Yaw Task
 * deadlock.
 * - Safety: Added `initFOC` success check & retry for Pitch Motor.
 * - Safety: Ignored `P` (Tracking) commands if Pitch is UNCALIBRATED (prevent
 * flywheel spin). v2.2.82 Changelog:
 * - Fix (Command): Corrected `P` command parsing. It was accidentally nested
 * inside `CAL,YAW` block. This fixes the "Pitch not reacting" issue. v2.2.76
 * Changelog:
 * - Fix (Tracking): Added ±60 deg limit check to `P` command handler to prevent
 * collisions. v2.2.75 Changelog:
 * - Tuning: Adjusted Gain for Tracking (Sync with Unit 1).
 * v2.2.74 Changelog:
 * - Feature: Re-enabled `Y` command for GridEye Tracking (interprets as
 * Incremental Yaw). v2.2.73 Changelog:
 * - Fix: Randomized Yaw startup delay (200-1000ms) to prevent simultaneous
 * inrush. v2.2.72 Changelog:
 * - Fix: Added retry logic (3 attempts) for Yaw Motor `initFOC` failure.
 * - Fix: Increased startup delay to 1000ms to prevent power sag collision with
 * Pitch Motor. v2.2.71 Changelog:
 * - Tuning: Damping (Inner P=0.5, Ki=0.15, Leak=0.95) to reduce oscillation.
 * v2.2.70 Changelog:
 * - Tuning: Gain Scheduling (Boost P=3.0 / Stable P=1.5).
 * - Unit 1 Fix: Increased Stack Size to prevent visual task crash.
 * v2.2.69 Changelog:
 * - Tuning: Boosted Acceleration (Outer P=2.5, Inner P=1.0, Ki=0.20) to fight
 * external drift.
 * - Tuning: Fixed "No Return" Drift by removing I-term Reset logic and widening
 * Error Clamp (45 deg). v2.2.67 Changelog:
 * - Tuning: Fixed Drift by Blocking Leak (0.96) and Boosting I-term (0.10).
 * - Target: Holds position against cable torque.
 * v2.2.66 Changelog:
 * - Tuning: Increased Virtual Friction (Leak=0.90) to prevent Windup during
 * slow moves. v2.2.65 Changelog:
 * - PID Tuning: Reduced P to 1.5 for Stability (Anti-Oscillation).
 * - Limits: Set Saturation to 150.0f (Physical Reality) to enable Unwind Logic.
 * v2.2.64 Changelog:
 * - Modified: OTA Source path.
 * v2.2.62 Changelog:
 * - PID Tuning: Increased Gains for Snappy Response (Inner P=1.0, Outer
 * P=4.0/D=0.15). v2.2.61 Changelog:
 * - Added 200ms delay to Yaw Task (Core 0) to stagger initialization (Power Sag
 * Fix).
 * - Removed ALL Serial prints (Setup, Loop, Cmd) to prevent Core 1 blocking.
 * v2.2.59 Changelog:
 * - Removed unauthorized delays. Added Heartbeat Diagnostic to detect Core 0
 * Hang.
 * - Removed Serial prints from Core 0 Yaw Task to prevent startup hang.
 * v2.2.56 Changelog:
 * - Refactoring: Moved Yaw Parsing outside Pitch Angle check (Fix for limp
 * motor).
 * - Refactoring: Enabled Yaw parsing from POS, Disabled separate Y command.
 * v2.2.54 Changelog:
 * - Removed Yaw Debug Prints to fix blocking issue when USB disconnected.
 * v2.2.53 Changelog:
 * - Added Yaw Debug Prints (Target, Current, Output).
 * v2.2.48 Changelog:
 * - Reverted YawController limits to 750 (safe value) to diagnose stopped motor
 * issue. v2.2.46 Changelog:
 * - Corrected YawController limits in setup to match library defaults
 * (Threshold=150). v2.2.37 Changelog:
 * - Added debug print for Y command verification.
 * v2.2.36 Changelog:
 * - Disabled Yaw update from POS command to prevent overwrite by upper program.
 * v2.2.35 Changelog:
 * - Improved Saturation Unwind Logic: Threshold=150, Decel=500, Leak=0.980.
 * v2.2.34 Changelog:
 * - Increased Auto-Cal speed to 14.0 rad/s.
 * v2.2.33 Changelog:
 * - Inverted Yaw Control Polarity (again) to fix stability at 180 deg.
 * v2.2.32 Changelog:
 * - Parallel Initialization: Yaw and Pitch motors calibrate simultaneously on
 * separate cores. v2.2.31 Changelog:
 * - Fixed Yaw Control Polarity: Inverted output for Reaction Wheel physics.
 * - Doubled Yaw Speed/Accel Limits (900rad/s, 750rad/s^2).
 * v2.2.30 Changelog:
 * - Fixed Yaw Control: Removed dependency on Pitch Calibration (Always Active).
 * v2.2.29 Changelog:
 * - Updated Yaw PID gains (P=1.0, I=0.02, D=0.05).
 * - Adjusted Auto-Cal sequence: 4s duration, 7.0 rad/s speed.
 * - Implemented 'SET_HORIZON' and 'CLEAR_CAL' for Pitch offset.
 * - Enforced sequential initialization (Core 1 -> Cmd -> Core 0).
 */

// --- OTA & WiFi Configuration ---
const char *ssid = "FU";
const char *password = "Spark!!!!!";
const char *ota_host =
    "comone-fragmented-unity-fw.s3.ap-northeast-1.amazonaws.com";
const int ota_port = 80;
const char *ota_bin = "/tube_v2_unit2_product.bin";

Preferences preferences;

// --- Pin Definitions (Unit 2) ---
#define PIN_RX D6 // UART1 RX from Unit 1
// Yaw Motor
#define YAW_U D4
#define YAW_V D5
#define YAW_W D3
#define YAW_SDA D9
#define YAW_SCL D10
// Pitch Motor
#define PITCH_PIN_A D2
#define PITCH_PIN_B D1
#define PITCH_PIN_C D0
#define PITCH_SDA D7
#define PITCH_SCL D8

// --- Objects ---
BLDCMotor motorYaw = BLDCMotor(7, 6.5f, 330.0f);
BLDCDriver3PWM driverYaw = BLDCDriver3PWM(YAW_U, YAW_V, YAW_W);
MagneticSensorI2C sensorYaw = MagneticSensorI2C(AS5600_I2C);

BLDCMotor motorPitch = BLDCMotor(7, 6.5f, 330.0f);
BLDCDriver3PWM driverPitch = BLDCDriver3PWM(PITCH_PIN_B, PITCH_PIN_A,
                                            PITCH_PIN_C); // Swapped A/B
TwoWire I2C_PITCH = TwoWire(1);
MagneticSensorI2C sensorPitch = MagneticSensorI2C(AS5600_I2C);

YawController yawController;

TaskHandle_t yawTaskHandle;

// --- Shared Globals (Volatile for Sync) ---
volatile float g_target_heading = 0.0f;
volatile float g_current_heading = 0.0f;
volatile bool g_imu_active = false;
volatile bool g_is_calibrated = false;

// Auto-Calibration Shared States
volatile int g_yaw_cal_state = 0; // 0:Idle, 1-4:Moves
volatile unsigned long g_yaw_cal_timer = 0;
volatile uint32_t g_yaw_heartbeat = 0;     // Diagnostic Heartbeat
volatile bool g_yaw_velocity_mode = false; // v2.2.86: Direct Velocity Control
volatile float g_yaw_target_velocity = 0.0f;

float g_pitch_offset = 0.0f; // Only accessed by Core 1

// --- Debug Global ---
bool g_debug_stream = false;
unsigned long g_last_debug = 0;

// --- Helper Functions ---
String getHeaderValue(String header, String headerName) {
  return header.substring(strlen(headerName.c_str()));
}

void execOTA() {
  Serial.println("[OTA] Starting Update Process...");
  // Stop Motors
  motorYaw.disable();
  motorPitch.disable();
  // Suspend Yaw Task if running
  if (yawTaskHandle != NULL) {
    vTaskSuspend(yawTaskHandle);
  }

  WiFi.begin(ssid, password);
  unsigned long start = millis();
  while (WiFi.status() != WL_CONNECTED) {
    if (millis() - start > 20000)
      return;
    delay(500);
  }

  WiFiClient client;
  if (!client.connect(ota_host, ota_port))
    return;

  client.print(String("GET ") + ota_bin + " HTTP/1.1\r\n" +
               "Host: " + ota_host + "\r\n" + "Cache-Control: no-cache\r\n" +
               "Connection: close\r\n\r\n");

  unsigned long timeout = millis();
  while (client.available() == 0) {
    if (millis() - timeout > 10000) {
      client.stop();
      return;
    }
  }

  long contentLength = 0;
  bool gotHeader = false;

  while (client.available()) {
    String line = client.readStringUntil('\n');
    line.trim();
    if (!line.length()) {
      gotHeader = true;
      break;
    }
    if (line.startsWith("Content-Length: ")) {
      contentLength = atol((getHeaderValue(line, "Content-Length: ")).c_str());
    }
  }

  if (!gotHeader || contentLength == 0)
    return;

  if (Update.begin(contentLength)) {
    size_t written = Update.writeStream(client);
    if (written == contentLength) {
      if (Update.end()) {
        Serial.println("[OTA] Success! Rebooting...");
        delay(1000);
        ESP.restart();
      }
    }
  }
}

// --- CORE 0: Yaw Motor Task ---
void yawMotorTask(void *pvParameters) {
  // Wait for stability (Replace Serial Print delay)
  // v2.2.73: Randomized Delay (200-1000ms) to prevent simultaneous inrush
  // current
  unsigned long delay_ms = random(200, 1001);
  vTaskDelay(delay_ms / portTICK_PERIOD_MS);

  // Serial.println("Yaw Task Started on Core 0. Initializing Yaw Motor...");

  // --- Yaw Motor Init (Core 0 Local) ---
  Wire.begin(YAW_SDA, YAW_SCL);
  Wire.setClock(100000); // v2.2.86: Slow I2C for Reliability (Fixed 1/5 fail?)
  Wire.setTimeOut(1000); // v2.2.85: Prevent Deadlock
  sensorYaw.init(&Wire);
  motorYaw.linkSensor(&sensorYaw);
  driverYaw.voltage_power_supply = 5.0f;
  driverYaw.init();
  motorYaw.linkDriver(&driverYaw);
  motorYaw.controller = MotionControlType::velocity;
  motorYaw.controller = MotionControlType::velocity;
  motorYaw.PID_velocity.P = 0.5f; // Revert to smooth 0.5f (Reduce Vibration)
  motorYaw.PID_velocity.I =
      0.0f; // v2.2.88: Disable I-term to prevent drift at 0 speed
  motorYaw.init();

  // v2.2.72: Retry Logic for Initialization Failure
  int retries = 0;
  while (retries < 3) {
    if (motorYaw.initFOC()) {
      motorYaw.enable();
      break;
    }
    retries++;
    vTaskDelay(500 / portTICK_PERIOD_MS);
  }

  // v2.2.86: Startup Diagnostic Check
  float check_angle = sensorYaw.getAngle();
  if (check_angle == 0.0f && sensorYaw.getVelocity() == 0.0f) {
    // Possible I2C failure (Stuck at 0?)
    // Try soft reset? Or just flag it. The LED will blink.
  }

  // Yaw Controller Settings (High Level)
  // v2.2.70: Gain Scheduling (Base P=1.5, Boost=3.0)
  // v2.2.71: Reduced Ki (0.15) and Inner P (0.5) for Damping.
  yawController.setPID(1.5f, 0.15f, 0.10f); // Base P=1.5, Ki=0.15
  yawController.setLimits(200.0f, 100.0f);

  // Serial.println("Yaw Motor Ready (Core 0). Starting Loop...");

  for (;;) {
    // 0. Update Heartbeat
    g_yaw_heartbeat++;

    // 1. FOC Loop (High Frequency)
    motorYaw.loopFOC();

    // 2. Control Logic
    // 2. Control Logic
    // Allow Yaw control independent of Pitch Calibration
    if (g_yaw_cal_state != 0) {
      // Auto-Calibration Sequence
      unsigned long now = millis();
      unsigned long elapsed = now - g_yaw_cal_timer;
      float cal_speed = 14.0f;

      if (g_yaw_cal_state == 1) {
        motorYaw.target = cal_speed;
        if (elapsed > 4000) {
          g_yaw_cal_state = 2;
          g_yaw_cal_timer = now;
        }
      } else if (g_yaw_cal_state == 2) {
        motorYaw.target = -cal_speed;
        if (elapsed > 4000) {
          g_yaw_cal_state = 3;
          g_yaw_cal_timer = now;
        }
      } else if (g_yaw_cal_state == 3) {
        motorYaw.target = cal_speed;
        if (elapsed > 4000) {
          g_yaw_cal_state = 4;
          g_yaw_cal_timer = now;
        }
      } else if (g_yaw_cal_state == 4) {
        motorYaw.target = -cal_speed;
        if (elapsed > 4000) {
          g_yaw_cal_state = 0;                  // Done
          g_target_heading = g_current_heading; // Prevent jump
        }
      } else if (g_yaw_velocity_mode) {
        // v2.2.88: Reverted Polarity (Negative Target) based on Log Analysis
        // v2.2.87 (+target) caused Runaway to Right on Left Command.
        motorYaw.target = -g_yaw_target_velocity;
      } else {
        // Normal Position Control (Always Active)
        static unsigned long last_yaw = 0;
        unsigned long now = millis();
        if (now - last_yaw > 20) { // 50Hz
          last_yaw = now;
          float current_vel = motorYaw.shaft_velocity;
          // Use local copies of volatiles
          float target_vel = yawController.update(
              g_current_heading, g_target_heading, current_vel);
          motorYaw.target = -target_vel; // INVERTED POLARITY
        }
      }

      // 3. Move
      motorYaw.move();

      // No delay to maximize performance
      // ESP32 Watchdog might trigger if loop is too tight, but loopFOC has some
      // overhead? If needed: vTaskDelay(1); but that kills FOC performance.
      // Ideally, SimpleFOC loop is fine.
      // Ideally, SimpleFOC loop is fine.
    }
  }
}

// --- Command Handler (Runs on Core 1) ---
void handleCommand(String cmd) {
  cmd.trim();
  if (cmd.length() == 0)
    return;

  if (cmd.equals("j")) {
    g_debug_stream = true;
  } else if (cmd.equals("s")) {
    g_debug_stream = false;
  } else if (cmd.equalsIgnoreCase("OTA,START")) {
    preferences.begin("system", false);
    preferences.putBool("ota_mode", true);
    preferences.end();
    ESP.restart();
  } else if (cmd.startsWith("PV,")) {
    float v = cmd.substring(3).toFloat();
    if (motorPitch.controller == MotionControlType::velocity)
      motorPitch.target = v;
  } else if (cmd.equalsIgnoreCase("CLEAR_CAL")) {
    g_pitch_offset = 0.0f;
    g_is_calibrated = false;
    preferences.begin("tube_v2", false);
    preferences.putFloat("p_off", 0.0f);
    preferences.end();
    motorPitch.controller = MotionControlType::velocity;
    motorPitch.target = 0.0f;
    Serial.println("CAL_CLEARED");
  } else if (cmd.equalsIgnoreCase("SET_HORIZON")) {
    float raw = sensorPitch.getAngle();
    g_pitch_offset = -raw; // (raw + off) = 0 -> off = -raw
    preferences.begin("tube_v2", false);
    preferences.putFloat("p_off", g_pitch_offset);
    preferences.end();
    g_is_calibrated = true;
    // Serial.println("CAL_OK_HORIZON. Offset=" + String(g_pitch_offset));
    motorPitch.target = motorPitch.shaft_angle;
    motorPitch.controller = MotionControlType::angle;
  } else if (cmd.startsWith("I,")) {
    g_imu_active = true;
    int p1 = cmd.indexOf(',');
    int p2 = cmd.indexOf(',', p1 + 1);
    int p3 = cmd.lastIndexOf(',');
    if (p1 > 0 && p2 > p1 && p3 > p2) {
      g_current_heading = cmd.substring(p1 + 1, p2).toFloat();
    }
  } else if (cmd.startsWith("POS,")) {
    String params = cmd.substring(4);
    int p1 = params.indexOf(',');
    if (p1 < 0)
      p1 = params.length();

    // 1. Yaw Control (Independent)
    // POS,Pitch,Yaw
    if (p1 < params.length()) {
      String yaw_str = params.substring(p1 + 1);
      if (yaw_str.length() > 0) {
        g_target_heading = yaw_str.toFloat();
        // v2.2.86: Any POS command restores Position Control
        g_yaw_velocity_mode = false;
      }
    }

    // 2. Pitch Control (Dependent on Calibration)
    if (g_is_calibrated)
      motorPitch.controller = MotionControlType::angle;

    if (motorPitch.controller == MotionControlType::angle) {
      float pitch_deg = params.substring(0, p1).toFloat();
      if (pitch_deg < -60.0f)
        pitch_deg = -60.0f;
      if (pitch_deg > 60.0f)
        pitch_deg = 60.0f;

      float target_phys = pitch_deg * (PI / 180.0f);
      motorPitch.target = target_phys - g_pitch_offset;
    }
  } else if (cmd.startsWith("Y")) {
    // v2.2.74: Re-enabled for Tracking (Incremental Move)
    // Unit 1 sends Y[val]. We add this to current target.
    // v2.2.86: Switch to Velocity Mode (Direct Speed Control)
    g_yaw_velocity_mode = true;
    g_yaw_target_velocity = cmd.substring(1).toFloat();
    // Sync Heading to prevent jump on exit
    g_target_heading = g_current_heading;
  } else if (cmd.equalsIgnoreCase("CAL,YAW")) {
    g_yaw_cal_state = 1;
    g_yaw_cal_timer = millis();
  } else if (cmd.startsWith("P")) {
    // v2.2.75: Incremental Pitch Command (Tracking)
    // Unit 1 sends P[val]. We add this to current target.

    // SAFETY CHECK (v2.2.84): Ignore if Uncalibrated
    // If we are in Velocity mode (Uncalibrated), `P` would set Velocity,
    // causing spin.
    if (!g_is_calibrated)
      return;

    // v2.2.76: Add Limit Check (±60 deg) - Physical Angle
    float inc = cmd.substring(1).toFloat();
    // Convert inc (degrees) to radians
    float inc_rad = inc * (PI / 180.0f);

    // Calculate New Physical Target (rad)
    float current_phys = motorPitch.target + g_pitch_offset;
    float new_phys = current_phys + inc_rad;

    // Clamp to ±60 deg (±1.047 rad)
    float limit_rad = 60.0f * (PI / 180.0f);
    if (new_phys > limit_rad)
      new_phys = limit_rad;
    if (new_phys < -limit_rad)
      new_phys = -limit_rad;

    // Set Target
    motorPitch.target = new_phys - g_pitch_offset;
  }
}

void setup() {
  Serial.begin(115200);
  Serial1.begin(115200, SERIAL_8N1, PIN_RX, -1);
  // v2.2.84: Set Timeout to 5ms to prevent blocking (Default 1000ms)
  Serial.setTimeout(5);
  Serial1.setTimeout(5);

  preferences.begin("system", false);
  bool ota_mode = preferences.getBool("ota_mode", false);
  if (ota_mode) {
    Serial.println("OTA Mode. Executing...");
    preferences.putBool("ota_mode", false);
    preferences.end();
    execOTA();
    ESP.restart();
  }
  preferences.end();

  pinMode(LED_BUILTIN, OUTPUT);
  digitalWrite(LED_BUILTIN, HIGH);

  // Serial.printf("Unit 2 Firmware v%s Booting...\n", FIRMWARE_VERSION);

  // --- 0. Start Yaw Task (Parallel Init) ---
  // Launch Core 0 task immediately so it initializes Yaw motor
  // while Core 1 initializes Pitch motor below.
  xTaskCreatePinnedToCore(yawMotorTask, "YawTask", 4096, NULL, 1,
                          &yawTaskHandle, 0); // Core 0

  // --- 1. Pitch Motor Init (Priority) ---
  I2C_PITCH.begin(PITCH_SDA, PITCH_SCL);
  I2C_PITCH.setTimeOut(1000); // v2.2.85: Prevent Deadlock
  sensorPitch.init(&I2C_PITCH);
  motorPitch.linkSensor(&sensorPitch);
  driverPitch.voltage_power_supply = 5.0f;
  driverPitch.init();
  motorPitch.linkDriver(&driverPitch);
  motorPitch.controller = MotionControlType::velocity;
  motorPitch.PID_velocity.P = 0.2f;
  motorPitch.PID_velocity.I = 2.0f;
  motorPitch.LPF_velocity.Tf = 0.02f;
  motorPitch.P_angle.P = 5.0f;
  motorPitch.velocity_limit = 20.0f;
  motorPitch.voltage_limit = 3.0f;

  preferences.begin("tube_v2", false);
  g_pitch_offset = preferences.getFloat("p_off", 0.0f);
  preferences.end();

  motorPitch.init();

  // v2.2.84: Retry Logic for Pitch Initialization
  int pitch_retries = 0;
  bool pitch_ready = false;
  while (pitch_retries < 3) {
    if (motorPitch.initFOC()) {
      pitch_ready = true;
      break;
    }
    pitch_retries++;
    // Serial.println("Pitch InitFOC Failed. Retrying...");
    delay(500);
  }

  if (!pitch_ready) {
    // Critical Failure: Disable Motor to prevent burn
    motorPitch.disable();
    // Serial.println("Pitch InitFOC FAILED. Motor Disabled.");
  }

  // motorPitch.initFOC(); // Blocking calibration (~2-3 sec)

  if (g_pitch_offset != 0.0f) {
    g_is_calibrated = true;
    // Serial.println("Pitch Calibrated.");
    motorPitch.controller = MotionControlType::angle;
    motorPitch.target = 0.0f - g_pitch_offset; // Hold Horizon
  } else {
    // Serial.println("Pitch NOT Calibrated.");
    motorPitch.target = 0.0f;
  }
}

void loop() {
  // --- Core 1: Pitch Control & Comm ---
  motorPitch.loopFOC();
  motorPitch.move();

  // LED Priority:
  // 1. Yaw Motor Disabled (Init Fail) -> FAST BLINK (50ms)
  // 2. Yaw Task Stuck (Heartbeat Fail) -> MEDIUM BLINK (100ms)
  // 3. Pitch Uncalibrated -> SLOW BLINK (200ms)
  // 4. Normal -> SOLID OFF (High)

  static uint32_t last_heartbeat_val = 0;
  static unsigned long last_heartbeat_check = 0;
  static bool yaw_stuck = false;

  if (millis() - last_heartbeat_check > 500) {
    if (g_yaw_heartbeat == last_heartbeat_val) {
      yaw_stuck = true;
    } else {
      yaw_stuck = false;
      last_heartbeat_val = g_yaw_heartbeat;
    }
    last_heartbeat_check = millis();
  }

  // Simplified Check
  if (!motorYaw.enabled) {
    static unsigned long last_fast_blink = 0;
    if (millis() - last_fast_blink > 50) {
      last_fast_blink = millis();
      digitalWrite(LED_BUILTIN, !digitalRead(LED_BUILTIN));
    }
  } else if (yaw_stuck) {
    static unsigned long last_med_blink = 0;
    if (millis() - last_med_blink > 100) {
      last_med_blink = millis();
      digitalWrite(LED_BUILTIN, !digitalRead(LED_BUILTIN));
    }
  } else if (!g_is_calibrated) {
    static unsigned long last_blink = 0;
    if (millis() - last_blink > 200) {
      last_blink = millis();
      digitalWrite(LED_BUILTIN, !digitalRead(LED_BUILTIN));
    }
  } else {
    digitalWrite(LED_BUILTIN, HIGH);
  }

  // Handle Communication
  if (Serial1.available())
    handleCommand(Serial1.readStringUntil('\n'));
  if (Serial.available())
    handleCommand(Serial.readStringUntil('\n'));

  // Debug Stream
  if (g_debug_stream && (millis() - g_last_debug > 100)) {
    g_last_debug = millis();
    float raw_rad = sensorPitch.getAngle();
    float raw_deg = raw_rad * 180.0f / PI;
    float cal_deg = (raw_rad + g_pitch_offset) * 180.0f / PI;
    // Serial.printf("D:%.2f,%.2f,%.1f,%.1f,%.1f\n", raw_deg, cal_deg,
    //               g_target_heading, g_current_heading,
    //               motorYaw.shaft_velocity);
  }
}

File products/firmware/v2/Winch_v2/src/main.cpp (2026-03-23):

/* ============================================================================
 *  _      ___          __
 * | | /| / (_)__  ____/ /
 * | |/ |/ / / _ \/ __/ _ \
 * |__/|__/_/_//_/\__/_//_/
 *
 *  FU Product Winch v2
 * ============================================================================
 * Role:
 * 1. Controls Winch Motor (Stepper + TMC2209)
 * 2. Communicates with Tube Unit 1 (UART) via Slip Ring
 * 3. Handles MQTT Command & Control
 * 4. Master controller for the entire kinetic unit
 * ============================================================================
 */

#include <AccelStepper.h>
#include <Adafruit_NeoPixel.h>
#include <Arduino.h>
#include <PubSubClient.h>
#include <TMCStepper.h>
#include <Update.h>
#include <WiFi.h>

#include "driver/temperature_sensor.h"
#include "esp_mac.h"
#include "esp_task_wdt.h"

#define FIRMWARE_VERSION "2.4.4"
  
/*
 * CHANGELOG
 * ============================================================================
 * v2.4.4 | 2026-02-11 | Optimization
 *   - [OPT] Increased motor voltage.
 *
 * v2.4.3 | 2026-02-09 | Optimization
 *   - [OPT] Removed RX_RAW debug monitor to improve performance/stability.
 *
 * v2.4.2 | 2026-02-09 | MQTT Task Separation
 *   - [NEW] Implemented dedicated FreeRTOS task (Core 0) for MQTT/WiFi.
 *   - [FIX] Removed blocking MQTT calls from main loop (Core 1).
 *   - [NEW] Added MqttMessage queue for thread-safe communication.
 *   - [FIX] Initialization order in setup() to prevent race conditions.
 *
 * v2.4.1 | 2026-02-09 | Calibration Tweak
 *   - [MOD] Increased CALIBRATION_OFFSET_STEPS to -1600 (~200mm).
 * ============================================================================
 */

#ifndef ENABLE_DEBUG_SERIAL
#define ENABLE_DEBUG_SERIAL // Enabled for debugging homing
#endif

#ifdef ENABLE_DEBUG_SERIAL
#define DEBUG_PRINT(x) Serial.print(x)
#define DEBUG_PRINTLN(x) Serial.println(x)
#define DEBUG_PRINTF(...) Serial.printf(__VA_ARGS__)
#define DEBUG_BEGIN(x) Serial.begin(x)
#else
#define DEBUG_PRINT(x)
#define DEBUG_PRINTLN(x)
#define DEBUG_PRINTF(...)
#define DEBUG_BEGIN(x)
#endif

// =============================================================================
// Pin Definitions
// =============================================================================
#define PIN_TUBE_TX 9      // UART TX to TUBE
#define PIN_TUBE_RX 8      // UART RX from TUBE
#define PIN_ONBOARD_LED 48 // ESP32-S3 onboard RGB LED (WS2812)
#define PIN_STATUS_LED 16  // Status LED strip (4x WS2812B)
#define PIN_LED_PWM 15     // 3W LED PWM control

// TMC2209 Stepper Motor Pins (from winch_esp32s3_dev_test)
#define PIN_TMC2209_EN 10   // Enable (active low)
#define PIN_TMC2209_TX 17   // UART TX
#define PIN_TMC2209_RX 18   // UART RX
#define PIN_TMC2209_STEP 13 // Step
#define PIN_TMC2209_DIR 14  // Direction

// Electromagnetic Brake / Solenoid (from winch_esp32s3_dev_test)
#define PIN_SOLENOID 3 // Brake control (active LOW: HIGH=unlock, LOW=lock)

// End Sensor (from winch_esp32s3_dev_test)
#define PIN_SENSOR 46    // End switch sensor (INPUT_PULLUP, LOW=triggered)
#define PIN_SENSOR_LED 7 // Endswitch detect LED

// PWM settings for 3W LED (Converted to 0.2W LED support)
// TPS92200D2 Driver requires 20kHz-200kHz PWM for analog dimming mode
#define PWM_FREQ 20000   // 20kHz
#define PWM_RESOLUTION 8 // 8-bit (0-255)

// Motor parameters (from v1 FU_WINCH_RP2040_U2)
#define WINCH_RADIUS                                                           \
  50 // mm (spiral winding effective radius - re-calibrated: 1800mm@77mm →
     // 2800mm@50mm)
#define STEPS_PER_REV 6400   // 200 steps/rev × 32 microsteps
#define MOTOR_MAX_SPEED 5000 // steps/sec (doubled from 5000)
#define MOTOR_MAX_ACCEL 5000 // steps/sec² (increased for faster response)
#define MAX_HEIGHT_MM                                                          \
  2800                // Maximum height in mm (calibration home position limit)
#define R_SENSE 0.11f // TMC2209 sense resistor
#define DRIVER_ADDRESS 0b00 // TMC2209 address

// Calibration parameters (from winch_rp2040_eval)
#define HOMING_SPEED 1000             // steps/sec (slow for safety)
#define CALIBRATION_TIMEOUT_MS 120000 // 2 minutes timeout
#define CALIBRATION_OFFSET_STEPS                                               \
  -1600 // 150mm offset after sensor detection (negative = away from sensor)

// StallGuard parameters (DISABLED - EndSwitch only homing)
// #define STALLGUARD_THRESHOLD 100
// #define STALLGUARD_TCOOLTHRS 0xFFFFF
// #define STALLGUARD_IGNORE_DURATION_MS 500

// Standalone mode parameters (WiFi接続失敗時のフォールバック動作)
#define STANDALONE_MODE_ENABLED                                                \
  false // スタンドアロンモード有効/無効 (true=有効, false=無効)
#define STANDALONE_MIN_HEIGHT_MM 500  // ランダム動作の最小高さ (mm)
#define STANDALONE_MAX_HEIGHT_MM 2500 // ランダム動作の最大高さ (mm)
#define STANDALONE_MIN_WAIT_MS 3000   // 到達後の最小待機時間 (ms)
#define STANDALONE_MAX_WAIT_MS 10000  // 到達後の最大待機時間 (ms)

// =============================================================================
// Configuration
// =============================================================================
const char *ssid = "FU";                 // WiFi SSID (venue/開発共通)
const char *password = "Spark!!!!!";     // WiFi Password
const char *mqtt_server = "192.168.1.2"; // Mac IP (Docker nanomq)
const int mqtt_port = 1883;

// TUBE UART
#define TUBE_SERIAL Serial1

// =============================================================================
// Global Objects
// =============================================================================
WiFiClient espClient;
PubSubClient mqttClient(espClient);
Adafruit_NeoPixel pixel(1, PIN_ONBOARD_LED, NEO_GRB + NEO_KHZ800);
Adafruit_NeoPixel statusLed(4, PIN_STATUS_LED,
                            NEO_GRB + NEO_KHZ800); // 4x status LEDs

// TMC2209 and AccelStepper (using Serial2 for ESP32-S3)
HardwareSerial TMC_SERIAL(2); // Use Serial2 for TMC2209
TMC2209Stepper driver(&TMC_SERIAL, R_SENSE, DRIVER_ADDRESS);
AccelStepper stepper(AccelStepper::DRIVER, PIN_TMC2209_STEP, PIN_TMC2209_DIR);

// =============================================================================
// OTA Variables (V1 implementation - simple and proven)
// =============================================================================
bool OTAprogress = false;
String otaHost = "comone-fragmented-unity-fw.s3.ap-northeast-1.amazonaws.com";
int otaPort = 80;
String otaBin = "/winch_v2/winch_v2_product.bin"; // S3 path to latest firmware
long contentLength = 0;
bool isValidContentType = false;
int retryCount = 0;
const int maxRetry = 20;

char macWithoutColons[13];
char deviceId[4] = "";
uint8_t deviceIdNumber = 0;
bool idAcquired = false;

// --- Forward Declarations ---
void processTubeLine(char *line);
void updateStatusLed();
void execOTA();
void performCalibration();
// ----------------------------
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

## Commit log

2025-10-14 Initial commit: setup project structure
    - Add README with project overview
    - Add arduino-pullup-resistor-lecture.md
    - Setup basic directory structure (docs, src, notes)
2025-10-14 fix: correct project information - Fragmentations of Unity
    - 誤: 地下鉄インスタレーション
    - 正: 名古屋市芸術創造センター 群ロボットインスタレーション
    - 企画書PDFを追加
    - README更新: コンセプト、技術仕様、チーム情報を正確に記載
2025-10-14 fix: correct venue information - Common Nexus (ComoNe)
    - 誤: 名古屋市芸術創造センター
    - 正: Common Nexus（ComoNe）
2025-10-16 docs: add evaluation board design task document
    ウインチ耐久性検証用簡易筒基板の設計タスクドキュメントを追加
    ## 概要
    - 期限: 2025-10-24 (JLCPCB発注締切)
    - 担当: 鈴木さん
    - 現地テスト: 2025-10-31
    ## 主要仕様
    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
2025-10-17 docs: update evaluation board design to 3-layer structure
    - Correct LED count: 96 NeoPixels (not 48)
    - 3 separate 2-layer PCB boards:
    - Grid Ring: Grid-EYE + 24 LEDs + DCDC 3.3V + 6 brass wires
    - Pitch Ring: RP2040 + 48 LEDs (24+24) + DCDC 5V + 12 brass wires
    - GY85 Ring: GY-85 IMU + 24 LEDs + DCDC 3.3V + 6 brass wires
    - Brass wire circular arrangement following eval_board.png
    - Updated task breakdown for 3-board design
2025-10-17 docs: add eval_board.png image to evaluation board design
    - Add 3-layer board structure image (eval_board.png)
    - Place image after board configuration overview section
    - Add image caption explaining Grid Ring, Pitch Ring, GY85 Ring structure
    - Highlight brass wire circular arrangement pattern
2025-10-17 docs: add TX/RX pinout and 4-pole jack configuration
    Audio transcription: 新規録音 35.m4a (2025-10-17)
    Key updates to evaluation-board-design.md:
    - Add UART cross-connection details (Winch TX → RP2040 RX, vice versa)
    - Add 4-pole stereo jack pin assignment (safety-focused):
    - Tip: 24V (first contact)
    - Ring1: TX from Winch → RP2040 RX (GPIO1)
    - Ring2: RX from Winch → RP2040 TX (GPIO0)
    - Sleeve: GND (last contact, prevents 24V short)
    - Add silk screen marking guidelines
    - Add Primary/Secondary (Master/Slave) concept explanation
    New document:
    - tx-rx-connector-pinout-instructions-2025-10-17.md
    - Detailed UART cross-connection principles
    - 4-pole jack pin order safety ra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
2025-10-17 docs: add stepper motor trace width analysis
    PCBトレース幅の問題を発見:
    - 現状: 10mil (許容0.5A)
    - モーター定格: 2.0A/相 (17HS24-2004D-B070)
    - 推奨: 35-50mil (1oz銅箔)
    リスク: 過熱、電圧降下、信頼性低下
2025-10-17 docs: add stepper motor trace width fix completion report
    修正完了:
    - 10mil → 40mil (suzukishohei対応)
    - 許容電流: 0.5A → 1.5A
    - 対応時間: 約8分（発見から完了まで）
    評価: 実用上問題なし、さらなる改善オプションあり
2025-10-17 docs: add comprehensive progress report and ESP32-S3 pinout documentation
    プロジェクト全体進捗レポート（PROGRESS.md）追加:
    - システムアーキテクチャV2設計完了
    - 電磁ブレーキ回路フェイルセーフ対応
    - ステッパーモータートレース幅問題解決（10mil→40mil）
    - ESP32-S3ピンアサイン確定（13本GPIO最適配置）
    - 今後の予定（基板発注～展示準備）
    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
2025-10-17 docs: add meeting notes and update progress with evaluation board design
    進捗共有ミーティング議事録追加（2025-10-17）:
    - Winch基板発注スケジュール確定（10/24締切、10/31到着）
    - 評価ボード設計方針決定
    - LED配置2パターン検証（点状 vs 中心集中）
    - ケーブルヒステリシス特性測定計画
    - リアクションホイール干渉確認
    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
2025-10-17 refactor: rename UART signals to functional names
    UART信号名を機能別にわかりやすく変更:
    - UART1_TX/RX → TUBE_TX/RX (筒側通信)
    - UART2_TX/RX → TMC_TX/RX (TMC2209診断)
    変更箇所:
    - ピンアサイン表
    - 機能別一覧
    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
2025-10-17 fix: correct meeting participants and AI collaboration stance
    修正内容:
    - 参加者: kyopan, かのさん（鈴木） → kyopan, 菅野さん, 鈴木さん
    - AIの使い方:
    - 信頼できる部分: コード生成を削除
    - 正しい方針: 自分主体でコード生成、理解できないコードはAIに任せない
2025-10-17 fix: correct schedule dates and remove milestone management rule
    - スケジュール訂正:
    - 10/24発注締切 → 10/20発注締切
    - 10/31基板到着 → 10/24基板到着
    - 11月上旬組み立て → 10/24〜組み立て・FWテスト開始
    - 追加: 10/31現地5台テスト開始
    - AI協働方針: 「締切とマイルストーンは人間が管理」を削除
    - 参照名修正: かのさん → 鈴木さん
    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
2025-10-17 feat: update evaluation board to 144 LEDs (48 per board)
    変更内容:
    - LED総数: 96個 → 144個
    - Grid Ring: 24個（裏のみ） → 48個（表裏各24）
    - GY85 Ring: 24個（裏のみ） → 48個（表裏各24）
    - Pitch Ring: 48個（変更なし）
    設計意図:
    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
2025-10-20 docs: restructure evaluation-board-design with hierarchical specs
    - Refactor main document from 601 to 347 lines (-42%)
    - Create specs/ subdirectory with 3 detailed specification documents:
    - circuit-specifications.md: DCDC circuits, ESD protection, NeoPixel plan
    - hardware-specifications.md: Board specs, sensors, wiring, parts list
    - pcb-layout-guide.md: Layout requirements, component placement, manufacturing
    - Add cross-references between documents for easy navigation
    - Correct NeoPixel total count: 96 → 144 LEDs
    - Improve readability with clear section hierarchy
2025-10-20 docs: add I2C pin assignments to evaluation board specs
    - Add I2C0 (GPIO4/5) for GY-85 sensor
    - Add I2C1 (GPIO26/27) for Grid-EYE sensor
    - Update Mermaid diagram with separate I2C buses
    - Update hardware specifications with detailed pin assignments
    - Update wire signal details with GPIO numbers
    - Clarify Pitch Ring has 12 wires (6 to Grid Ring + 6 to GY85 Ring)
2025-10-20 docs: add GPIO pin details to wire signal blocks in Mermaid diagram
    - Add SDA1 GPIO26/SCL1 GPIO27 to Grid Ring wire block
    - Add SDA0 GPIO4/SCL0 GPIO5 to GY85 Ring wire block
    - Makes pin assignments visible at a glance in the diagram
2025-10-20 docs: add SDA/SCL pin details to RP2040 I2C specifications
    - I2C0: SDA=GPIO4 SCL=GPIO5 (GY-85)
    - I2C1: SDA=GPIO26 SCL=GPIO27 (Grid-EYE)
2025-10-21 docs: add document change notification rule
    ドキュメント変更通知ルールを追加
    - 仕様・要件の削除/変更時にSlack通知必須
    - FU-Nagoya専用スレッド方式（チャンネル汚染防止）
    - CICが自動サポート（変更タイプ判定、テンプレート生成）
    - 専用スレッド: https://kyopalab.slack.com/archives/C0806K7E9RD/p1761018893032439
2025-10-21 docs: add PCB silkscreen naming rules
    PCBシルクスクリーン命名規則を追加
    主要内容:
    - 信号方向明示の原則（"from"表記）
    - UART TX/RXのクロス接続表記
    - 4極ステレオジャックピン配置（安全性重視）
    - フォント・サイズ推奨値
    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
2025-10-21 docs: add bridge connection labeling rule to silkscreen spec
    PCBシルクスクリーン命名規則 v1.1.0
    追加内容:
    - 原則4: ブリッジ接続端子のラベル位置・向き一致ルール
    - 真鍮線等で基板同士を接続する場合の命名ルール
    - 接続先基板と端子ラベルの位置・向きを一致させる
    - 貫通線の接続先を明確にする
    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
2025-10-21 docs: update UART terminal notation to arrow + simple format
    PCBシルクスクリーン命名規則 v1.2.0
    - UART端子表記を業界標準準拠の形式に変更
    - 旧: "TX from Winch" / "RX from Winch"
    - 新: "Winch TX →" / "Winch RX ←"
    理由:
    - 業界標準（TX/RX は自分視点）に準拠
    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
2025-10-23 Add evaluation board wiring discussion documentation
    評価ボード配線ディスカッションの詳細ドキュメントを追加:
    - 音声文字起こし（約20分の議論内容）
    - 手書きスケッチ画像（評価ボード設計案）
    - 音声ファイル（オリジナル録音）
    主な内容:
    - ミラーリング廃止による配線シンプル化
    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
2025-10-23 Update evaluation board design: fix NeoPixel wiring (brass wire 1)
    重要な設計変更:
    - 真鍮線1を貫通配線から部分配線に変更（PR↔GRのみ）
    - GRとCRの同時点灯問題を解決
    - PRの配線最適化とシルクラベル改善
    詳細: notes/audio-transcriptions/evaluation-board-wiring-discussion.md
2025-10-23 Update evaluation board design: add NeoPixel wiring critical fix
    ⚠️ 重要な設計変更（2025-10-23 午後）
    - NeoPixel真鍮線1を貫通配線→部分配線に変更
    - PR ↔ GR のみ接続、CRへは非接続
    - 問題: GRとCRが同時点灯（個別制御不可）を解決
    追加改善:
    - PR配線最適化（真鍮線1端子を最寄り位置に配置）
    - PR真鍮線1端子を2端子化（ジャンパー選択）
    - シルクラベル改善（PRR/PRF/GRF/CRF大きく表示）
    詳細: notes/audio-transcriptions/evaluation-board-wiring-discussion.md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
2025-10-23 Add Figma wiring diagram to evaluation board design
    新機能:
    - 最新のFigma配線図を追加（2025-10-23）
    - Actual wiring（実際の配線）を可視化
    - Wiring diagram（NeoPixelチェーン144個の論理接続）を可視化
    配線図の内容:
    - 青線: NEO Din（PR → GR のみ、CR側は "Not connected"）
    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
2025-10-23 Remove outdated 3D structure image from evaluation board design
    削除内容:
    - 古い3層基板構造イメージ（eval_board.png）を削除
    - 最新のFigma配線図（2025-10-23）に完全移行
    - 古い画像は最新の部分配線設計を反映していない
    - 新しいFigma配線図が実際の配線を正確に可視化
    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
2025-10-23 Critical design change: Switch to through-hole connection method
    ⚠️ 根本的な問題を発見・解決（2025-10-23 最終版）
    問題:
    - PRとCR/GRの配線がNeoPixelのDin/Doutにぶつかる
    最終解決策:
    - PRのNeoPixel貫通穴を削除
    - スルーホール接続方式に変更
    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
2025-10-23 Add PCB thickness and color specifications
    新規追加仕様:
    - 基板板厚仕様を追加
    GR/CR: 1.0mm（共用基板）
    PR: 1.6mm（より頑丈な構造）
    - 基板色: 全て白色
    詳細:
    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
2025-11-13 feat(fu-v2): add BLDC + Variable Resistor Pitch control test firmware
    ## 主要変更
    ### ファームウェア追加
    - `products/firmware/v2/Test/BLDC_VR_Test/` - Pitch制御テストコード
    - BLDCモーター + 可変抵抗 50kΩによる位置制御
    - SimpleFOC v2.3.4使用
    - ESP32-S3 GPIO10 ADC読取
    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
    [BLDC2206.stp, FU稼働時間2025_8-10.xlsx - 詳細データ.csv, WSSB40-30-5.stp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]
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2025-11-18 docs: update RP2040 upload method clarification
    - Clarify that BOOTSEL button is NOT required for normal uploads
    - PlatformIO picotool automatically performs soft reset
    - Document when BOOTSEL mode is needed (rare cases only)
    - Add specific upload commands for winch_rp2040_eval_test and tube_rp2040_eval_test
    🤖 Generated with [Synthitect](https://kyopalab.com)
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2026-03-23 feat(fu): Add missing Winch_v2 firmware files
    - platformio.ini, .gitignore, .vscode/extensions.json
    - scripts/upload_to_s3.py, upload_to_s3_wrapper.py
    - src/ota_handler.cpp, ota_handler.h
    - docs/images/winch-status-led-diagram.png
    - specs/winch_v2_specification.md
    - S3_UPLOAD_README.md, build_and_upload.sh, monitor.sh
    [upload_to_s3.py, upload_to_s3_wrapper.py]

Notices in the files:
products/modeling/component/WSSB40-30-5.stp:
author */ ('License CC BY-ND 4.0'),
